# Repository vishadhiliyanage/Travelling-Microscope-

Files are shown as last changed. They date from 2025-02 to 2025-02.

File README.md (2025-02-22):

# Travelling-Microscope 
This project creates a 1 ft³ traveling microscope with a sliding mechanism, vernier scale, and rotatable microscope. Using workshop tools like lathes and milling machines, it enhances precision engineering skills. The cost-efficient, adjustable, and durable design supports scientific research, education, and local manufacturing innovation.

# 📌 Table of Contents  

## ⚙️ Manufacturing and Assembling  
- 🔹 [`Base`](#base)  
- 🔹 [`Vertical Pillar or Column`](#vertical-pillar-or-column)  
- 🔹 [`Microscope Body or Barrel`](#microscope-body-or-barrel)  
- 🔹 [`Screw and Nut Mechanism`](#screw-and-nut-mechanism)  
- 🔹 [`Fine Adjustment Knob`](#fine-adjustment-knob)  
- 🔹 [`Main Scale and Vernier Scale`](#main-scale-and-vernier-scale)  
- 🔹 [`Lens Holders`](#lens-holders)  

## 🎨 Physical Appearance  
- 🖼️ [`View and Design`](#physical-appearance)  

## 📊 Results and Discussion  
- 📈 [`Findings`](#results-and-discussion)  

## 🏆 Conclusion  
- ✅ [`Achievements`](#achievements)  
- 📏 [`Accuracy and Uncertainty`](#accuracy-and-uncertainty)  
- ⚡ [`Advantages`](#advantages)  
- 🎯 [`Applications`](#applications)  

## 📎 Appendices  
- 📂 [`Additional Information`](#appendices)

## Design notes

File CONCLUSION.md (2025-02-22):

## Achievements:
The successful creation of a traveling microscope equipped with both coarse and fine adjustments in the vertical
direction was achieved as the final outcome of the project.
Accuracy and Uncertainty:
The least count of the travelling microscope = 0.05 mm
Instrument error = ± 0.05 mm
User uncertainty = ± 0.02mm
Accuracy and uncertainty = user uncertainty + least count = ± 0.07mm
## Advantages:
• Compact and Lightweight Design: The device's compact and lightweight design facilitates easy
transportation, ensuring portability and convenience.
• User-Friendly Operation: With an easily learnable measuring mechanism, even beginners with no prior
knowledge can use the device effortlessly, making it accessible to a wide range of users.
• Cost-Effective and Durable: The traveling microscope is an affordable option with low material costs and
a robust build, ensuring durability in harsh environments.
• Minimal Maintenance Requirements: Constructed primarily from metals like steel and galvanized iron,
the device requires minimal maintenance, cleaning, and storage facilities, offering long-lasting reliability
with little effort.
• Onsite Operation for Real-Time Decisions: The device allows for onsite operation, enabling immediate
measurements and real-time decision-making, streamlining processes, and enhancing efficiency.
• Non-Invasive Measurement: The measuring process ensures that the object under examination remains
untouched, preventing any compression or damage, preserving the integrity of the subject.
• Zero Operating Electric Power: Operating without the need for electricity, the device offers cost savings
and environmental friendliness, making it an efficient and sustainable option.

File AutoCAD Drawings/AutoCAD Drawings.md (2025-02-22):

<figure>
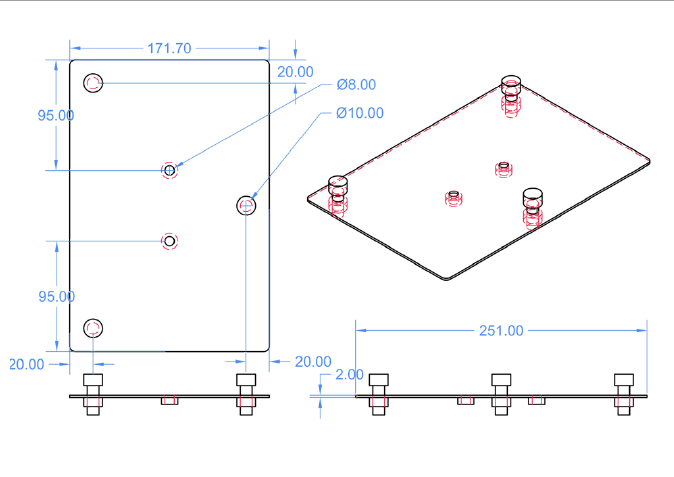
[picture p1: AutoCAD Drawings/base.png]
Base
  
  <figcaption>Base</figcaption>
</figure>
<p>&nbsp;</p>
<figure>
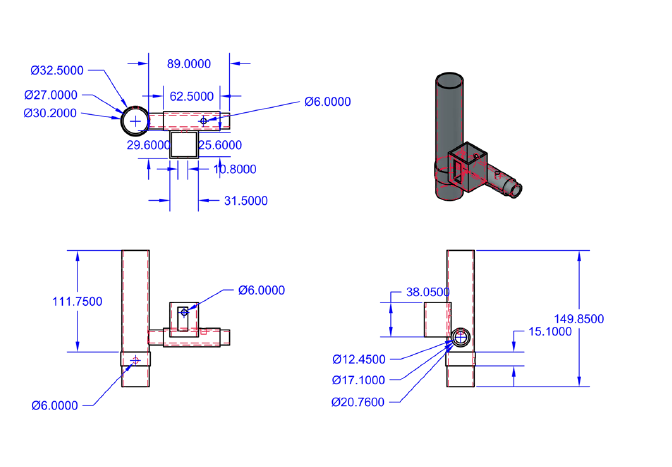
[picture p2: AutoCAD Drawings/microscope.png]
Microscope
  
  <figcaption>Microscope</figcaption>
</figure>
<p>&nbsp;</p>
<figure>
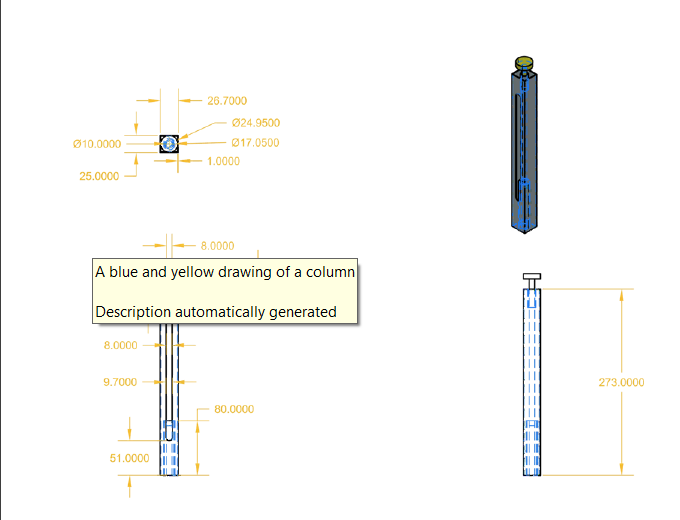
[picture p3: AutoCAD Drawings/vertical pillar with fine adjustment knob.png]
vertical pillar with fine adjustment knob
  
  <figcaption>vertical pillar with fine adjustment knob</figcaption>
</figure>
<p>&nbsp;</p>
<figure>
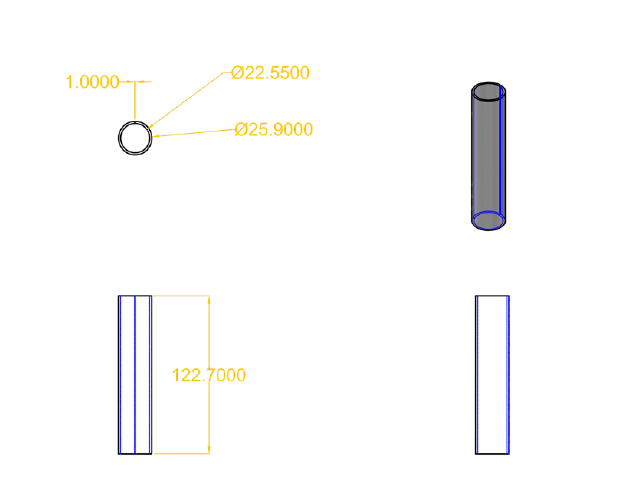
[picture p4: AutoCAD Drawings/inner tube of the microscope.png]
inner tube of the microscope
  
  <figcaption>inner tube of the microscope</figcaption>
</figure>
<p>&nbsp;</p>
<figure>
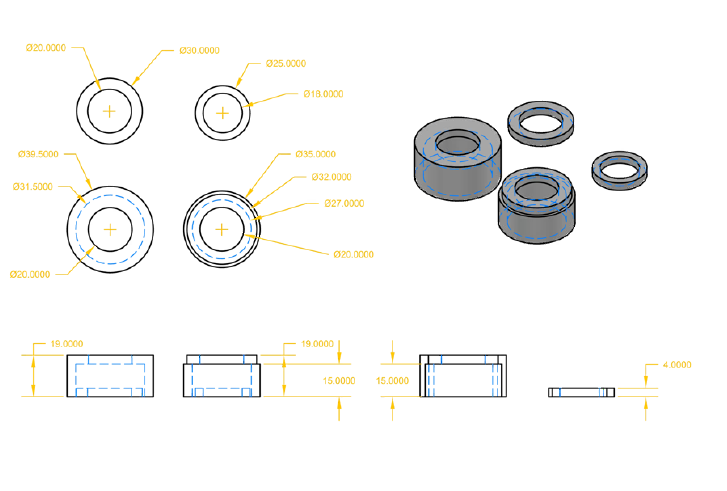
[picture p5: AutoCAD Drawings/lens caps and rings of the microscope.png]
lens caps and rings of the microscope
  
  <figcaption>lens caps and rings of the microscope</figcaption>
</figure>
<br>

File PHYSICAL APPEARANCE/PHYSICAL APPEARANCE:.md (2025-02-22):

<p align="center">
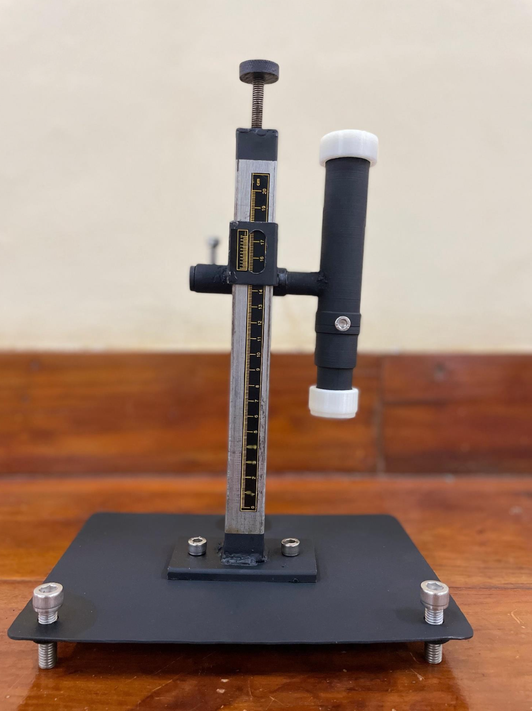
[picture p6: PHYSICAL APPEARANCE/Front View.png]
Front View
  
  <br>
  <em>Front View</em>
</p>

<p align="center">
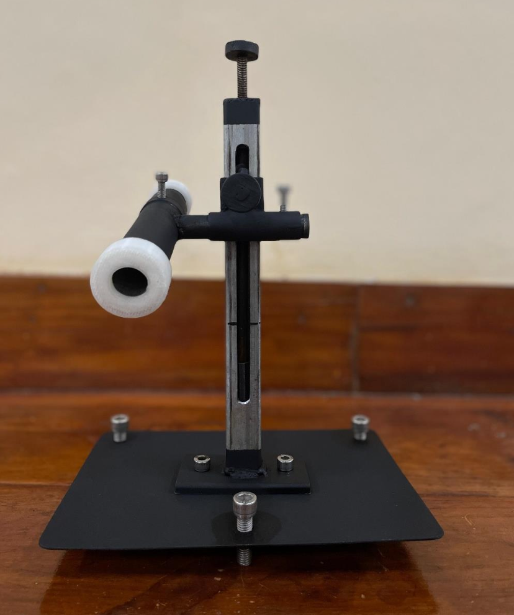
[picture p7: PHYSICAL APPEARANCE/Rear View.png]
Rear View
  
  <br>
  <em>Rear View</em>
</p>

<p align="center">
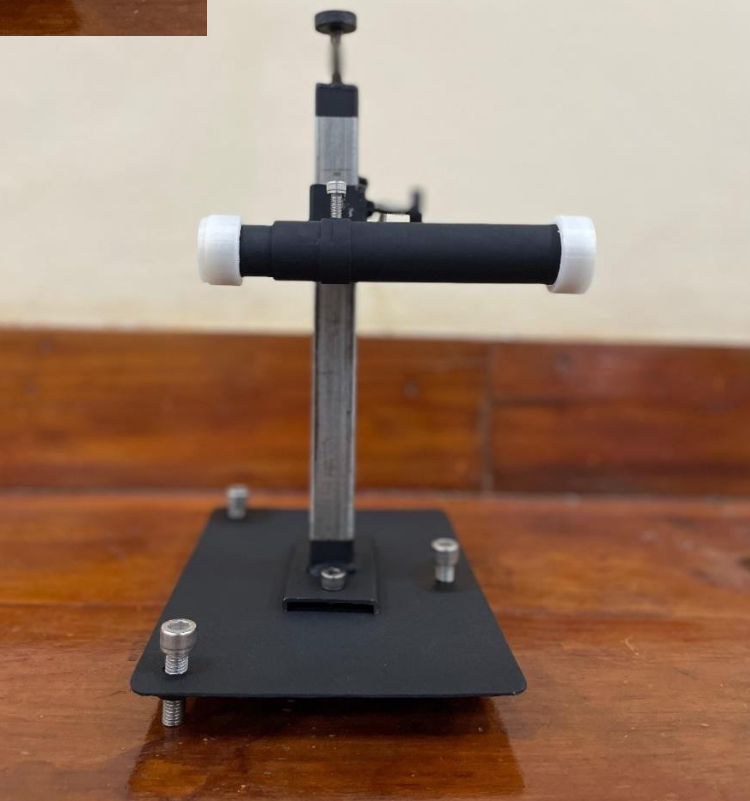
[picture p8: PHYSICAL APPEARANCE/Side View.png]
Side View
  
  <br>
  <em>Side View</em>
</p>

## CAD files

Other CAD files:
AutoCAD Drawings/Telescope Scale.dwg
AutoCAD Drawings/lens cap.dwg
AutoCAD Drawings/Vertical Section.dwg

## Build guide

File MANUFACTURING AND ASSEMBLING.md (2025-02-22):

<div style="text-align:center;">
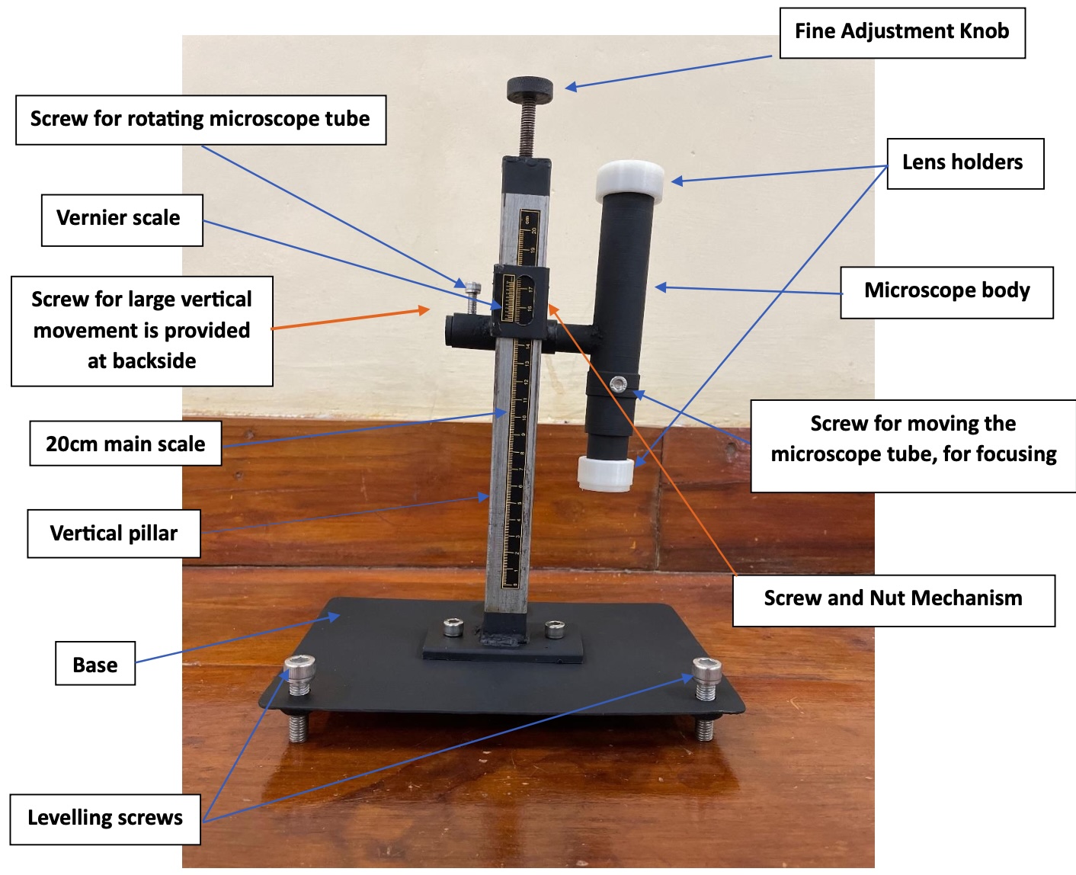
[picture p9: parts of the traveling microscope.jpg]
Parts of the Traveling Microscope
  
  <p><b>Parts of the Traveling Microscope</b></p>
</div>

## **Base**
The base provides stability and support for the entire microscope. It is usually a heavy and flat structure to ensure  
the instrument remains steady during measurements.

- Initially, a detailed design for the base was created, taking into consideration the dimensions of the  
  microscope components and the stability needed.
- Then the metal plate was cut according to the design by using a grinder.
- The edges and corners of the metal plate were smoothed using a metal file.
- The locations for holes needed to mount the vertical pillar and other components of the microscope  
  were identified.
- These holes were drilled using an appropriate-sized drill bit.
- The microscope components were assembled onto the base, securing them in place with screws and bolts.

## **Vertical Pillar or Column**
The vertical pillar or column rises from the base and provides vertical support for the rest of the microscope  
components. It is an essential part of the structural framework.

- Primarily, a detailed design for the vertical pillar was created, considering the required height, stability,  
  and any specific features.
- The box bars were cut according to the design using a bar cutter machine or hacksaw.
- The locations for holes needed were marked and those holes were drilled using an appropriate-sized drill bit.
- Then the thin slot was made by using the milling machine.
- The edges and corners of the box bars and thin slot were smoothed using a metal file.
- Then the interior mechanism of the pillar was designed, considering the functionality required for  
  adjusting the height of the microscope body.
- A spring was used to assist in raising or lowering the microscope body.
- The appropriate location for the spring within the mechanism was identified and a hollow cylinder was  
  used to maintain a proper movement of the spring.
- Then the hollow cylinder was welded to the bottom of the vertical pillar and the spring was placed inside  
  the cylinder.
- An iron rod was used to keep the smooth vertical movement of the microscope body.
- Then the microscope body was attached to the iron rod using an iron bush and a bolt. Large movement  
  of the microscope body can be done by tightening and loosening this screw.

## **Microscope Body or Barrel**
The microscope body houses the optics, including the objective lens and eyepiece. It is attached to the vertical  
pillar and can be moved up or down for focusing.

- Primitively, a design for the body or barrel was created, considering the required dimensions and specifications.
- Attention was given to accommodating the optical components and providing structural stability.
- Metal pipes were cut to the desired lengths based on the design specifications, using metal cutting tools  
  such as a hacksaw, angle grinder, or metal cutting bandsaw.
- The cut metal pipes were shaped as per the design requirements using metalworking tools.
- This involved removing sharp edges by using a metal file; a smooth and even surface was created using a  
  lathe machine.
- Then a groove was created to prevent rotation around the axis of the inner barrel. A milling machine was  
  used for this task.
- As the necessary mechanism to adjust the focus length, a hole was made on the outer barrel and a screw  
  was inserted through it.
- The various components, including lenses and eyepieces, were assembled onto the metal pipes.
- Then the outer barrel was welded perpendicularly to another iron rod using a welding machine, and that  
  whole system was attached to the vertical pillar.
- The assembled metal pipes were checked for any sharp edges or imperfections.
- Any irregularities were addressed, and the surface was finished to ensure a polished and professional appearance.

## **Screw and Nut Mechanism**
The microscope's movement is controlled by a screw and nut mechanism. This allows precise and controlled  
motion along the vertical pillar, enabling accurate focusing on the specimen.

- A design for the screw and nut mechanism was created, considering the required precision and control  
  for the movement of the microscope along the vertical pillar. Then a metal box was made to be slightly  
  larger than the vertical pillar. A suitable screw was chosen based on strength and durability.
- To attach the end of the screw, a metal knob was built.
- The appropriate knurling tool for the desired knurl pattern was chosen.
- The lathe speed was adjusted to a moderate speed suitable for knurling, and the knurling tool was  
  positioned on the metal rod, ensuring it was aligned perpendicular to the axis of the rod.
- The lathe was started, and cutting oil or lubricant was applied to the metal rod and knurling tool to reduce  
  friction and heat generation during the knurling process.
- The knurling process was repeated with adjustments to the tool pressure or feed rate until the desired  
  knurl pattern was achieved.
- Once the knurling was complete, any burrs or rough edges from the ends of the knurled section were  
  removed using a file.
- Then threads were cut into the metal box using thread-cutting tools, and the knob was welded to the end  
  of the screw.
- The assembled screw and nut mechanism underwent thorough testing to ensure smooth and controlled  
  motion along the vertical pillar of the microscope.
- Once installed onto the vertical pillar of the traveling microscope, the large movement of the microscope  
  body could be controlled by tightening and loosening the screw.

## **Fine Adjustment Knob**
The fine adjustment knob allows for precise focusing of the image. It is used to make small adjustments to the  
position of the microscope body for accurate measurements.

- Using a similar procedure, a fine adjustment screw was made and installed onto the vertical pillar at the top.
- Using this knob, small adjustments to the position of the microscope body can be operated.

## **Main Scale and Vernier Scale**
Traveling microscopes often include scales and verniers for measuring the linear dimensions of the specimen.  
These scales are typically graduated and can be read with high precision.

- Both main and vernier scales were designed using AutoCAD.
- The drawing settings, including units, grid, and dimensions, were configured according to the requirements  
  of the vernier scale design.
- The appropriate drawing tools, such as lines, circles, and text, were selected from the AutoCAD toolbar.
- The main scale was designed by drawing a straight line with the appropriate length and marking the  
  divisions corresponding to the measurement units.
- The vernier scale was drawn parallel to the main scale, by dividing 19mm into 20 parts (smallest  
  measurement can be taken = 0.05mm).
- Numerical values representing the measurement units were added to both the main scale and the vernier  
  scale using text tools in AutoCAD.
- The completed vernier scale design was saved in the desired file format and printed as a sticker. Then  
  the scale was stuck onto the vertical pillar.

## **Lens Holders**
- The lens holders were also designed using AutoCAD software.
- The appropriate design tools in AutoCAD, such as lines, circles, and 3D modeling features, were selected  
  for creating the lens holders.
- The measurements and specifications of the microscope's lenses were analyzed to ensure the accurate  
  design of the lens holders.
- Multiple designs for the lens holders were sketched in AutoCAD, considering factors such as shape and size.
- Once the designs were finalized, they were exported from AutoCAD in a compatible file format, such as  
  STL or OBJ, for 3D printing.
- The prepared design files were transferred to the 3D printer, and the printing process was initiated.
- The 3D printer manufactured the lens holders layer by layer using the chosen printing material.
- After printing was completed, the lens holders were inspected for any defects and installed onto the  
  microscope assembly.

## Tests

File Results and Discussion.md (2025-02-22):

• Many specimens have vertical features or structures that are of particular interest for examination. Vertical movement allows users to navigate through different layers or depths within the specimen, facilitating thorough examination and analysis. Because of that we decided to make a travelling microscope with vertical movement.

• Initially we decided to use thread bar to assemble the microscope body to vertical pillar, but in that case, we were unable to make large vertical movement of microscope body. As a solution, we decided to use metal rod and a spring to assemble microscope body, instead of thread bar. Springs provide a controlled and consistent force, allowing for both large vertical movement and fine vertical movement of the microscope body.

• The vertical adjustment process was simplified by springs, making it easier for users to manipulate the microscope body or lens assembly. This ease of use was enhanced by springs, particularly in high-throughput or time-sensitive microscopy tasks, improving efficiency and productivity.

• The focusing mechanism of a traveling microscope typically involves a system of knobs and screws that allow users to adjust the position of the microscope's lens to the specimen being observed.

• This mechanism enables users to achieve precise focusing for clear and detailed observation. By tightening and loosening the large vertical movement screw, the large movement of the microscope body can be done. Then using the fine movement knob, precise vertical movement of the microscope body can be performed.

• The vernier scale was designed by dividing 19mm of main scale into 20 parts (smallest measurement can be taken = 0.05mm). Numerical values representing the measurement units were added to both the main scale and the vernier scale, using text tools in AutoCAD.

• While using the welding machine the materials to be welded should be cleaned and prepared before starting the welding process. Remove any dirt, rust, or contaminants from the surfaces using wire brushes or grinding tools. Otherwise, it would be caused by poor weld quality. And attention should be paid to properly aligning and clamping the workpieces to ensure they are held securely in position during the welding process.

• While cutting or drilling the metal bars, boxes, or plates, they should be securely held in place stably using clamps or a vise. It was ensured that the workpiece was stable and wouldn't shift during cutting, minimizing the risk of inaccuracies or accidents.

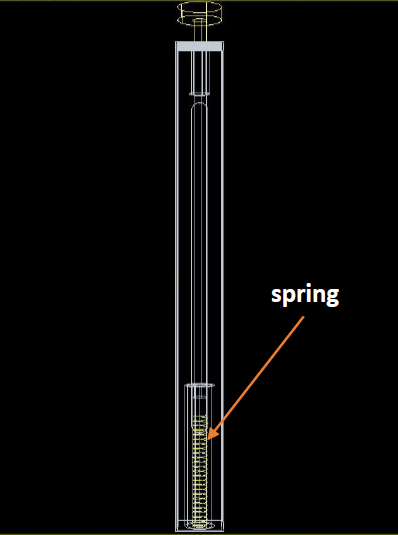
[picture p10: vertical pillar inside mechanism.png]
Vertical pillar inside mechanism


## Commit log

2025-02-22 Create # MANUFACTURING AND ASSEMBLING
2025-02-22 Rename # MANUFACTURING AND ASSEMBLING to MANUFACTURING AND ASSEMBLING
2025-02-22 Update MANUFACTURING AND ASSEMBLING
2025-02-22 Rename MANUFACTURING AND ASSEMBLING to MANUFACTURING AND ASSEMBLING.md
2025-02-22 Update MANUFACTURING AND ASSEMBLING.md
2025-02-22 Rename lens cap.dwg to AutoCAD Drawings/lens cap.dwg
    [lens cap.dwg]
2025-02-22 Rename Telescope Scale.dwg to AutoCAD Drawings/Telescope Scale.dwg
    [Telescope Scale.dwg]
2025-02-22 Rename Vertical Section.dwg to AutoCAD Drawings/Vertical Section.dwg
    [Vertical Section.dwg]
